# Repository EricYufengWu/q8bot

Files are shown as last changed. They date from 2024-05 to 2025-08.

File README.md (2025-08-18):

# Q8bot Quadruped

**03/03/2025 Update: Q8bot is now a research project at the [UCLA Robotics and Mechanisms Lab (RoMeLa)](https://www.romela.org/). The open-source nature of this project remains unchanged. We are working on an improved version of this platform and will potentially release it under a different name. Stay tuned!** 

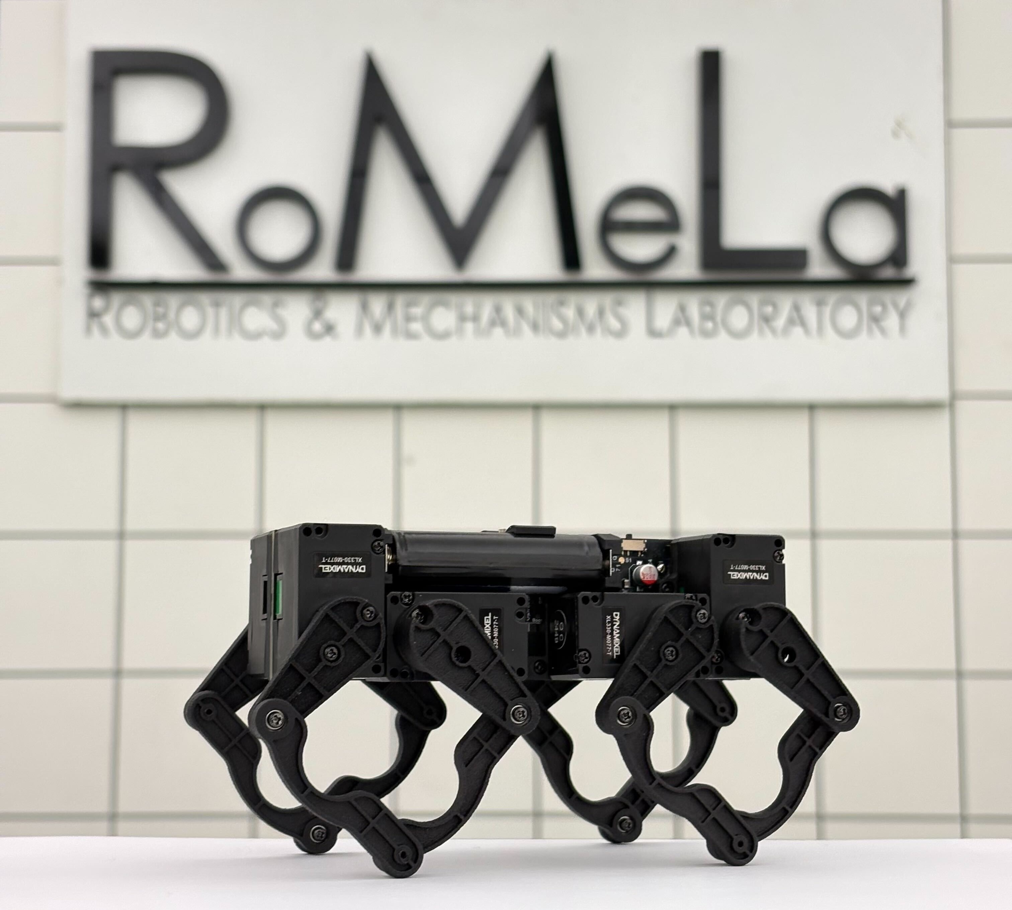
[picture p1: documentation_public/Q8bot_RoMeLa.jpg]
Q8bot (https://www.romela.org/)


## Featured Media & Demos

Q8bot was recently featured in a [tour video](https://youtu.be/FAo-BCnxW9A?si=LB-HlDlHGtaq-xd7&t=1208) by UnrealScience, a famous Korean science Youtube channel.

[This video](https://youtu.be/0dk7lYoITQw) demonstrates the latest capabilities of the robot, made possibly by ongoing improvements in software control and mechanical design.

See the detailed robot building process on [YouTube](https://youtu.be/YJDc1xAhaOI)!

Q8bot is lucky to be featured in a number of blog posts:
- Hackaday: https://hackaday.com/2024/10/29/little-quadruped-has-pcb-spine-and-no-wiring/#comments
- Hackster.io: https://www.hackster.io/news/a-step-up-for-diy-robotics-8b04a2320861?f=1
- Interesting Engineering: https://interestingengineering.com/innovation/palm-sized-quadruped-robot-redefines-design
- Techblog: https://www.techeblog.com/spot-robot-dog-q8bot/

## Publications
- Design: https://arxiv.org/abs/2508.01149
- Control & Data Acquisition: https://ieeexplore.ieee.org/abstract/document/11078123/

## Overview

Q8bot is a miniature quadruped robot with the size and weight comparable to a modern smartphone. This robot is capable of dynamic movements like walking, trotting, bounding, jumping, and more. It also has NO WIRES AND CABLES - everything is directly plugged into the center PCB, greatly reducing complexity, weight, and cost. The current **[Bill of Materials (BOM)](https://docs.google.com/spreadsheets/d/1M1K_Dghia-Mn2t4RStW8juN6r4e3I3OBy6M_fPFHzs8/edit?usp=sharing)**, without optimization, starts below $300. 

<p align="center">
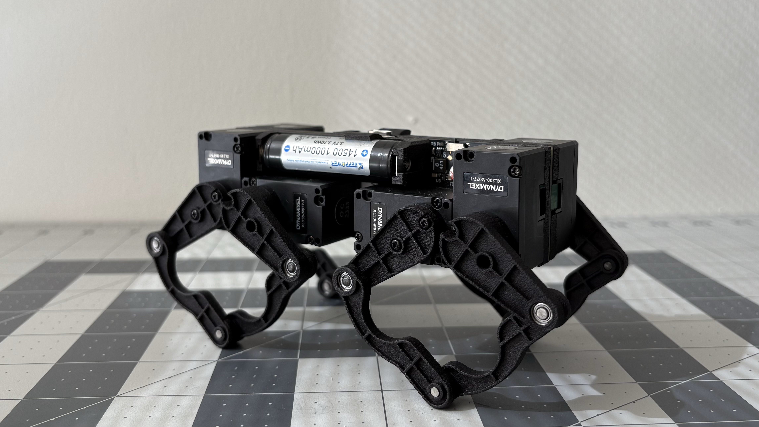
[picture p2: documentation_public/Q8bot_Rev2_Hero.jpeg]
  
  
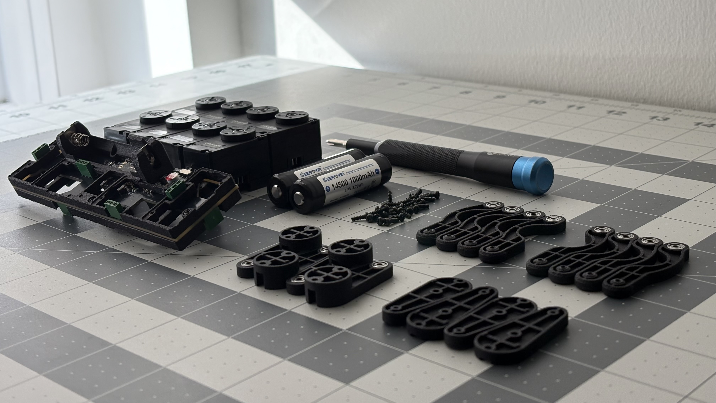
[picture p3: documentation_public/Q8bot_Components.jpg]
  
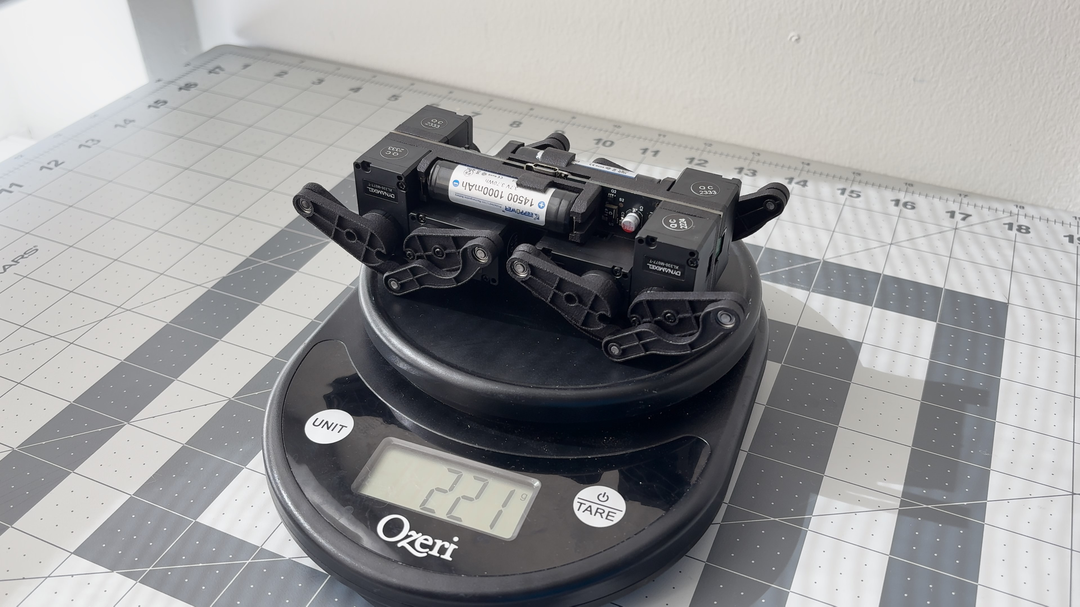
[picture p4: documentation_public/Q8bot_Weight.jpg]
  
</p>

Q8bot is 100% open source: In this repository, you will find everything you need - STEP, STL, Gerber, Schematics, bill of materials (BOM), instructions, and more - to build your own version. 

**You can now ordered the fully-assembled PCB via PCBWay!** This [project page](https://www.pcbway.com/project/shareproject/Q8bot_PCB_Robot_dfa65114.html) contains all of the assembly-related files (BOM, centroid, etc.) and simplifies the ordering process.

<p align="center">
    <a href="https://www.pcbway.com/project/shareproject/Q8bot_PCB_Robot_dfa65114.html">PCB from PCBWay</a>
</p>

I’m working on turning Q8bot into a purchasable kit, though I’m not sure when or if it will happen. In the meantime, I encourage you to build your own Q8bot! This palm-sized quadruped is perfect for robotics education, swarm robotics research, or simply as a fun engineering project. If you have any questions, feel free to reach out and I will try my best to help. 

Personal: yufeng.wu0902@gmail.com

School: ericyufengwu@ucla.edu

## Building Instruction

The building instructions have moved to a dedicated folder:

[Sourcing Components](building_instructions/sourcing_components.md)

[Assembling the Robot](building_instructions/robot_assembly.md)

[Software Setup](building_instructions/software_setup.md)

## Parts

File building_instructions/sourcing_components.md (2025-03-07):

# Components Sourcing Instructions

[**Sourcing Components**]()

[Assembling the Robot](robot_assembly.md)

[Software Setup](software_setup.md)

[Back to Project Page](https://github.com/EricYufengWu/q8bot)

**The complete bill of materials (BOM) of Q8bot can be accessed [here](https://docs.google.com/spreadsheets/d/1M1K_Dghia-Mn2t4RStW8juN6r4e3I3OBy6M_fPFHzs8/edit?usp=sharing)**. The links and prices are mainly for purchasing within the US. To accommodate different users, we've set up multiple "tiers" based on the tools you might have available. Please read the following sections carefully to choose the build configuration that works best for you. 

The BOM of this robot is so short that I can afford to explain every single component in detail :D

## Required Tools
This instruction assumes you have the following tools at a minimum:
- A PH-0 or JIS-1 screwdriver (I an iFixit Mako Driver Kit).
- A soldering iron with basic consumables (I used a Pinecil V2).
- A modern laptop capable of running Microsoft Visual Studio Code.
- A USB Type-A to Type-C (or Type-C to Type-C) cable for uploading firmware.
- Some masking tape or similar.

## Off-The-Shelf Components
These are the components you need to purchase regardless of build configurations.

[Dynamixel XL330-M077-T](https://www.robotis.us/dynamixel-xl330-m077-t/): You need a total of **8 motors** for the robot. Each motor comes with a set of M2 self-tapping screws, which will be used to assemble Q8bot.
<p align="center">
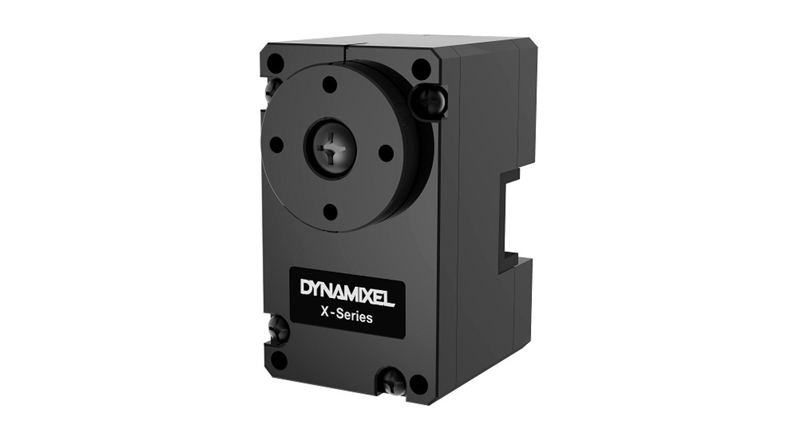
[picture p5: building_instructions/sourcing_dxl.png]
Dynamixel XL330-M077-T
    
</p>

[692ZZ Ball Bearing](https://www.amazon.com/uxcell-Groove-Bearings-Double-Shielded/dp/B082PR238V/ref=sr_1_2): You need a total of **12 bearings** with the trade number **692ZZ** (2mm x 6mm x 3mm). At the time of this writing, Amazon only sells them for pack of 10, so you'll end up with some extras. You can probably find cheaper alternatives on AliExpress or Ebay - any bearing with the same dimensions will work.

<p align="center">
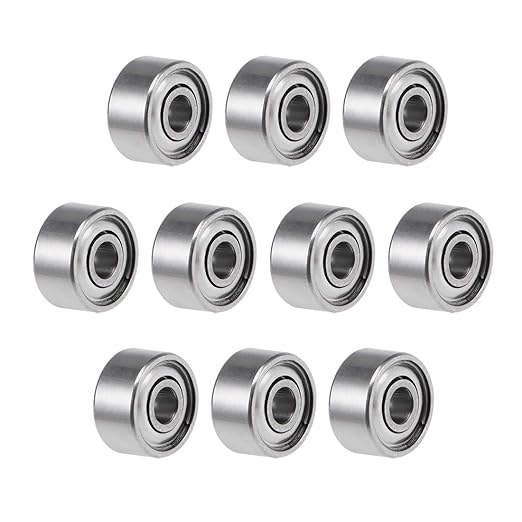
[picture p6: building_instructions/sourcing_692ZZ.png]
692ZZ Bearing
    
</p>

[14500 KeepPower 1000mAh P1450C2](https://illumn.com/14500-keeppower-1000mah-p1450c2-protected-button-top.html): You need **2 batteries** to run the robot and can purchase more pairs for hot-swapping. Keep in mind that these are Lithium-ion batteries in a AA form-factor, but **regular AA batteries will not work**. This particular model also has a built-in protection circuit so it is safer to work with.

<p align="center">
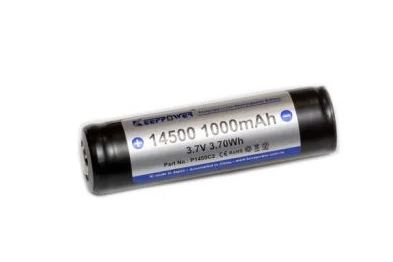
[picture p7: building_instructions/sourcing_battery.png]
KeepPower Battery
    
</p>

## Main PCB
There are two options for acquiring the main PCB for Q8bot.

### Option 1: Purchase A Fully-Assembled Board from PCBWay
  [This link](https://www.pcbway.com/project/shareproject/Q8bot_PCB_Robot_dfa65114.html) takes you to a PCBWay project page, contains all of the assembly-related files (BOM, centroid, etc.). You can simply  select "PCB+Assembly" and order the fully-assembled PCB (including headers and the micro-controller).

<p align="center">
    <a href="https://www.pcbway.com/project/shareproject/Q8bot_PCB_Robot_dfa65114.html">PCB from PCBWay</a>
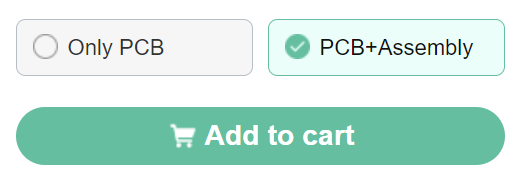
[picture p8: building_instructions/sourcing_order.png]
Ordering
    
</p>

However, you will still need to purchase some battery clips which will go into the 3D-printed main frames to hold the batteries. [This link](https://www.digikey.com/short/8w05tttf) directs you to a DigiKey shopping cart that contains 2x 1087-1 and 2x 1087-2 from Keystone Electronics.

<p align="center">
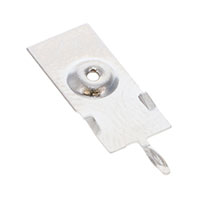
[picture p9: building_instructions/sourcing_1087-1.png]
    
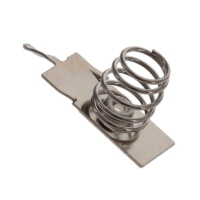
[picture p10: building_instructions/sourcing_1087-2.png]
    
</p>

### Option 2: Purchase Components and Reflow Yourself
You can order the blank PCB from JLC, PCBWay, or similar, and order the components separately to assemble the PCB youself. The zipped Gerber files, along with a read-friendly pick-and-place file, can be found under the `/PCBA` folder. Remember to also order stencils (top and bottom) when purchasing the blank PCBs. 

I used a [MHP50](https://www.adafruit.com/product/5903) mini hot plate and a stencil holder setup similar to [this one](https://youtu.be/F9zNtQTpbms?si=rfB_CtxsjbDME_TU). See my [YouTube video](https://youtu.be/YJDc1xAhaOI) for details. 

<p align="center">
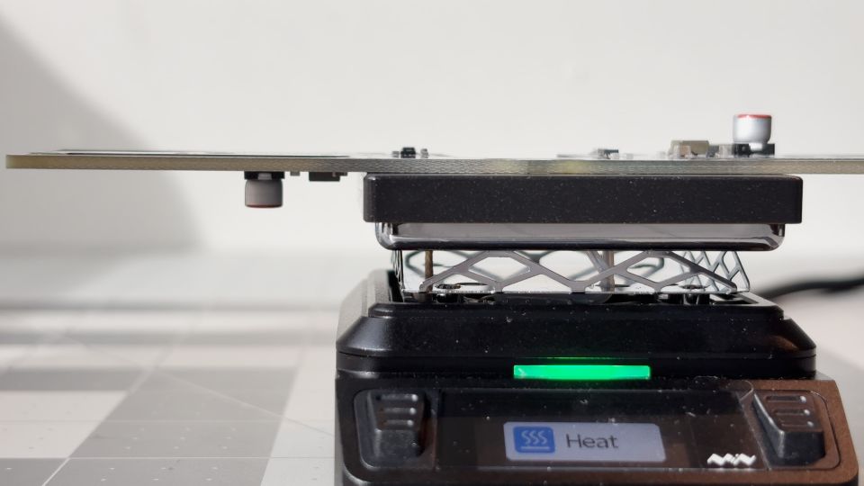
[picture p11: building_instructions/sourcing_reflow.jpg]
Reflow
    
</p>

[This link](https://www.digikey.com/short/n7vrz77m) directs you to a DigiKey shopping cart that contains all required PCB components, including the battery clips from earlier.

## 3D-Printed Parts
There are 2 options for 3D-printing parts for Q8bot. Regardless of outsourcing or printing them yourselves, you will need the following quantity to build 1x Q8bot. It never hurts to print/order some extras in case the robot breaks.
- `Q8bt_Frame`: Print 2.
- `Q8bot_LL_Left`: Print 4.
- `Q8bot_LL_Right`: Print 4.
- `Q8bot_UL1`: Print 4.
- `Q8bot_UL2`: Print 4.

### Option 1: Order MJF parts from Online Vendors
Multi Jet Fusion (MJF) is an isotropic 3D-printing technology similar to SLS. Many domestic and international companies offer printing service with relatively affordable price. To order, you typically need to upload the .STL files in the `/CAD/Q8_VX.X_MJF` folder to the vendor's website and configure the materials and quantity. I ordered the MJF parts together with my JLCPCB order to simplify the purchasing process.

### Option 2: 3D-Print Yourself using FDM
If you own a Bambu Lab, Prusa, or similar 3D-printer, you can print the parts yourself by downloading and slicing the files under `/CAD/Q8_VX.X_FDM`. I printed mine on a Bambu Lab A1 mini with the default 0.12mm settings. **The cost of filament is less than $1 for a $20 spool.**

Here is a table comparing MJF and FDM 3D-printed parts:

| MJF Outsourcing | FDM Print-it-Yourself |
|---|---|
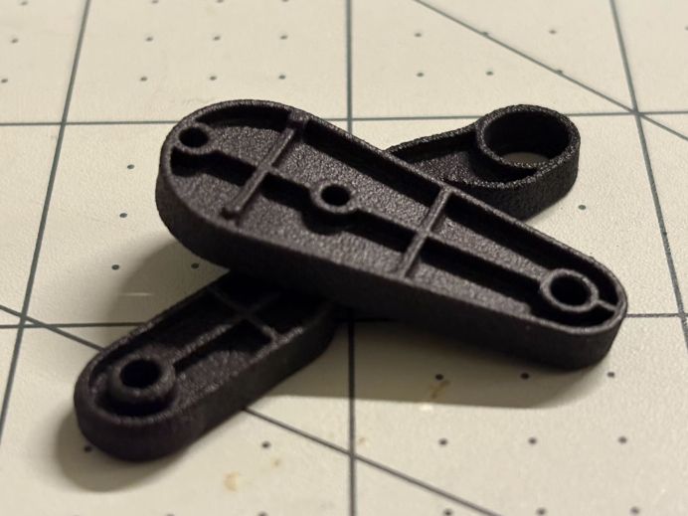
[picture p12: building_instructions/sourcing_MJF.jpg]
|  ||
| More expensive :x: | Less expensive :white_check_mark: |
| Saves time :white_check_mark: | Takes more time :x: |
| Surface finish gives a "product" vibe :white_check_mark: | Visible layer lines on parts :x: |
| Has extra geometry that makes assembly easier :white_check_mark: | No extra geometry :x: |
| Difficult to replace :x: | Easy to re-print and modify :white_check_mark: |
| Breaks first to protect motors* | Motors might break due to transferred impact* |

_*Not rigorously tested. Robot survives 1-meter drop during preliminary testing_

## Other Recommended Components
**Li-ion battery charger:** If you don't already have one, you probably also want to pick up a charger like [this one](https://www.amazon.com/EBL-Battery-Charger-Rechargeable-Technology/dp/B01D9TUL8Y/). In the future, I plan to add battery charging functionality to the PCB in the next iteration so you no longer have to buy a separate charger.

**ESPNow Dongle:** The current software architecture uses an ESP32C3 microcontroller connected to the laptop to wirelessly communicate with the robot. You can build an optional USB dongle by following instructions [here](https://github.com/EricYufengWu/ESPNowDongle). 

<p align="center">
    Dongle
</p>

**Dynamixel U2D2:** DYNAMIXELs are smart servo motors that require configuration to work properly on Q8bot. I’ve provided a simple firmware that guides you through the required setup without extra hardware (see [robot_assembly](robot_assembly.md)). However, for easier debugging and troubleshooting, I highly recommend purchasing the [U2D2](https://www.robotis.us/u2d2/) and [U2D2 Power Hub](https://www.robotis.us/u2d2-power-hub-board-set/). This setup allows you to configure individual DYNAMIXEL motors directly from your laptop, which is more convenient compared to using the ESP32.

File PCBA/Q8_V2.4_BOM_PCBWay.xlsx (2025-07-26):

 |  |  | Q8_V2.3 BOM
Item # | *Designator | *Qty | Manufacturer | *Mfg Part # | Description / Value | *Package/Footprint | Type | Your Instructions / Notes
1 | R8 | 1 | YAGEO | RC0603FR-0722RL | RES 22 OHM 1% 1/10W 0603 | 0603 | SMD | Generic chip resistor OK
2 | R1 | 1 | YAGEO | RC0603FR-07200RL | RES 200 OHM 1% 1/10W 0603 | 0603 | SMD | Generic chip resistor OK
3 | R2, R3, R4, R6, R7 | 5 | YAGEO | AF0603FR-0710KL | RES 10K OHM 1% 1/10W 0603 | 0603 | SMD | Generic chip resistor OK
4 | R5, R9 | 2 | YAGEO | AC0603FR-071KL | RES 1K OHM 1% 1/10W 0603 | 0603 | SMD | Generic chip resistor OK
5 | C1 | 1 | YAGEO | CC0603KRX7R8BB104 | CAP CER 0.1UF 25V X7R 0603 | 0603 | SMD | Generic >25V X5R/X7R capacitors OK
6 | C2, C3, C7, C8 | 4 | YAGEO | CC0805KKX5R8BB106 | CAP CER 10UF 25V X5R 0805 | 0805 | SMD | Generic >25V X5R/X7R capacitors OK
7 | C5 | 1 | YAGEO | CC0603KRX5R8BB105 | CAP CER 1UF 25V X5R 0603 | 0603 | SMD | Generic >25V X5R/X7R capacitors OK
8 | C6 | 1 | YAGEO | CC0603KRX7R9BB103 | CAP CER 10000PF 50V X7R 0603 | 0603 | SMD | Generic >25V X5R/X7R capacitors OK
9 | C4, C9 | 2 | Würth Elektronik | 865080342006 | CAP ALUM 47UF 20% 16V SMD | Radial, Can - SMD | SMD
10 | D1 | 1 | Lite-On Inc. | LTST-C190KRKT | LED RED CLEAR CHIP 0603 | 0603 | SMD | Generic red clear LED OK
11 | D2 | 1 | Onsemi | NSR0320MW2T1G | DIODE SCHOTTKY 20V 1A SOD323 | SC-76, SOD-323 | SMD
12 | Q1, Q2 | 2 | Onsemi | MCH6351-TL-W | MOSFET P-CH 12V 9A 6MCPH | 6-MCPH | SMD
13 | S1 | 1 | E-Switch | EG1215AA | SWITCH SLIDE SPDT 25MA 24V | Switch SMD | SMD
14 | U2 | 1 | Nexperia | 74LVC2G241GT,115 | IC BUFFER NON-INVERT 5.5V | 8XSON | SMD
15 | U3, U5 | 2 | Texas Instruments | TPS610333DRLR | IC REG BOOST ADJ 5A | SOT583 | SMD
17 | U4 | 1 | Maxim Integrated | MAX17043G+T | IC 2-WIRE FG MODEL GAUGE LO BATT | 8-TDFN | SMD
18 | L1, L2 | 2 | Coilcraft | XGL4020-471MEC | FIXED IND 470NH 19.7A 5.1MOHM SM | 1616 | SMD
19 | U1 | 1 | Seeed | 113991054 | SEEEDSTUDIO XIAO ESP32C3 NO HDRS | SMD | SMD | Please solder the component upside-down, so that the buttons and USBC connectors faces down. Hand-soldering is ok for this component.
20 | J1 - J8 | 8 | TE Connectivity | 215297-3 | RECEPTACLE STRIP 3P 2.54MM PITCH | 1x3 2.54mm | Through-hole | Height range of the header must be between 7mm and 7.9mm. Please note the silkscreen marking side is where the components should be placed. The soldering joints should be at the opposite side of the silkscreen. There are a total of 8 connectors, 4 on each side according the the silkscreen markings.
21 | J9 | 1 | JST | BM04B-SRSS-TBT(LF)(SN) | CONN HEADER SMD 4POS 1MM | JST SH | SMD | Alternative manufacturer OK
22 | BT1, BT2 | 2 | Custom | NA | Custom battery part | NA | DNP | Do not place
Need a quick and accurante quote? Need an efficient production? Please read SMT Ordering Necessary Files & Info in 1 minute. Thank you very much! (https://www.pcbway.com/smt_ordering_guide.html)
Click for Instructions on How to Create a BOM (https://www.pcbway.com/blog/PCB_Assembly/How_to_Build_a_BOM__Bill_Of_Materials_.html)

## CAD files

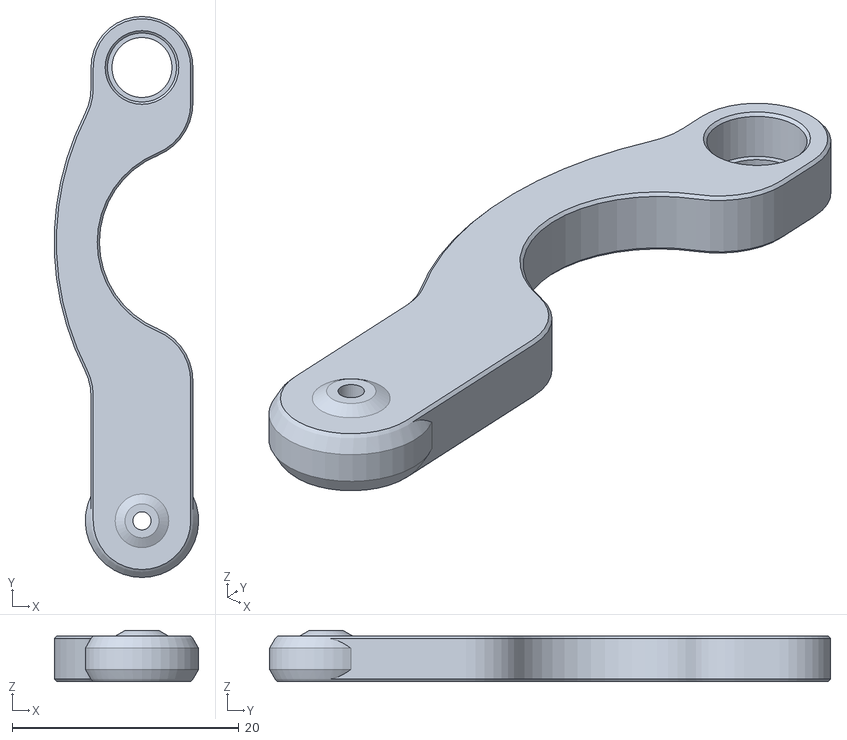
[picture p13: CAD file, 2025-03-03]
CAD/Q8_V2.4_FDM/PLA_Lower_Leg_Right_PRINT4.STL
12.7 x 49.5 x 4.50

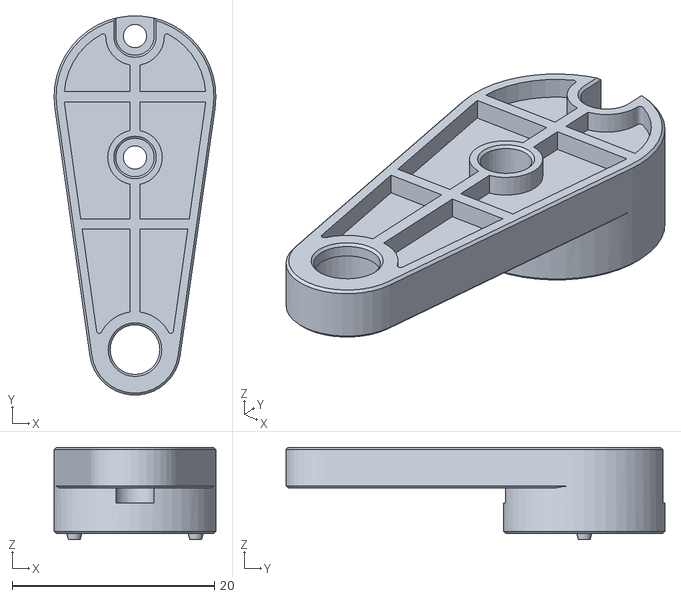
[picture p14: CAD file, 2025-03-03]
CAD/Q8_V2.4_MJF/MJF_Upper_Leg_Tall_PRINT4.STL
16.0 x 37.5 x 9.10

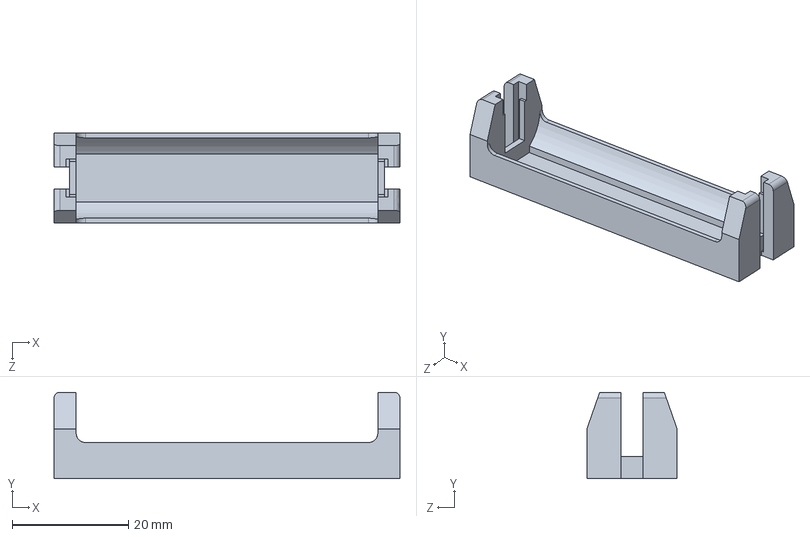
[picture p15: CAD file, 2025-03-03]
CAD/SolidWorks Source File/Batt_Case_keystone-PN1087_20250303export.SLDPRT
59.4 x 14.9 x 15.5 mm

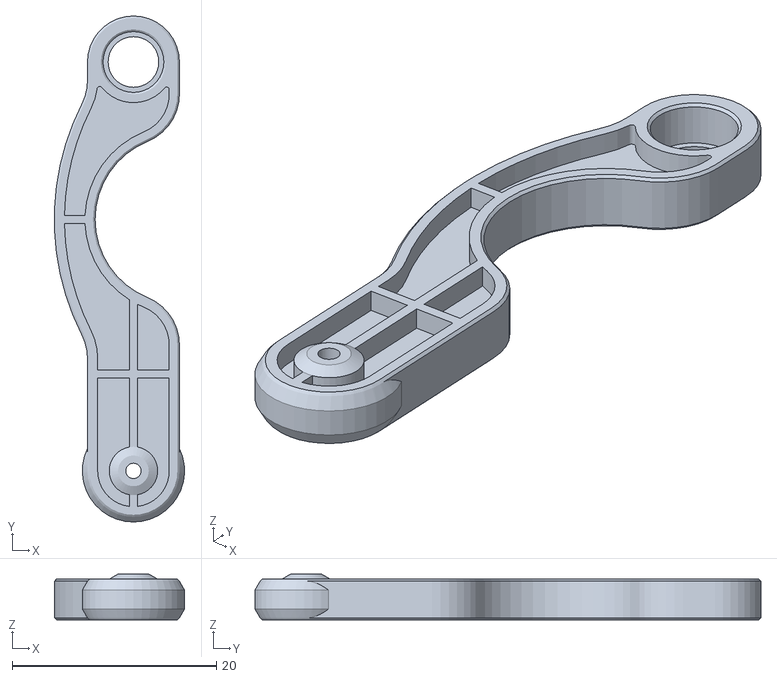
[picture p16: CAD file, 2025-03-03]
CAD/Q8_V2.4_MJF/MJF_Lower_Leg_Right_PRINT4.STL
12.7 x 49.5 x 4.50

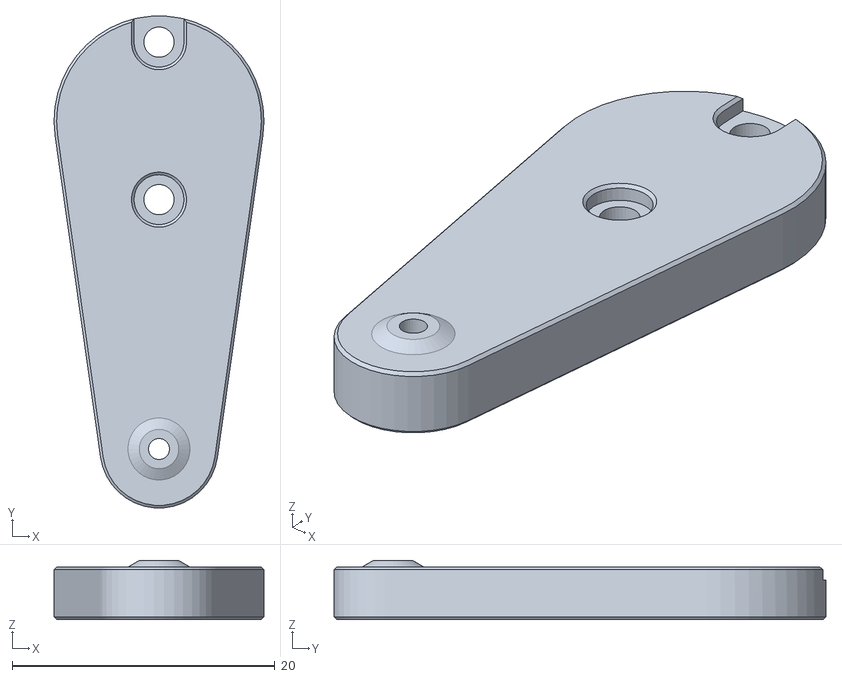
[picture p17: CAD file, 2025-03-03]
CAD/Q8_V2.4_FDM/PLA_Upper_Leg_Short_PRINT4.STL
16.0 x 37.5 x 4.50

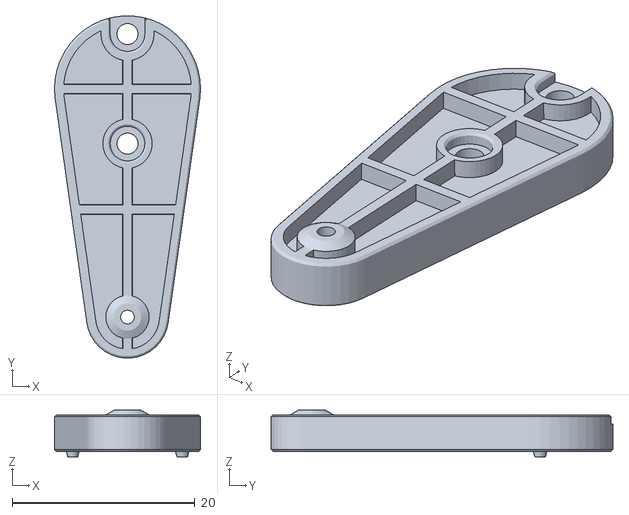
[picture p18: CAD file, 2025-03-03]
CAD/Q8_V2.4_MJF/MJF_Upper_Leg_Short_PRINT4.STL
16.0 x 37.5 x 5.10

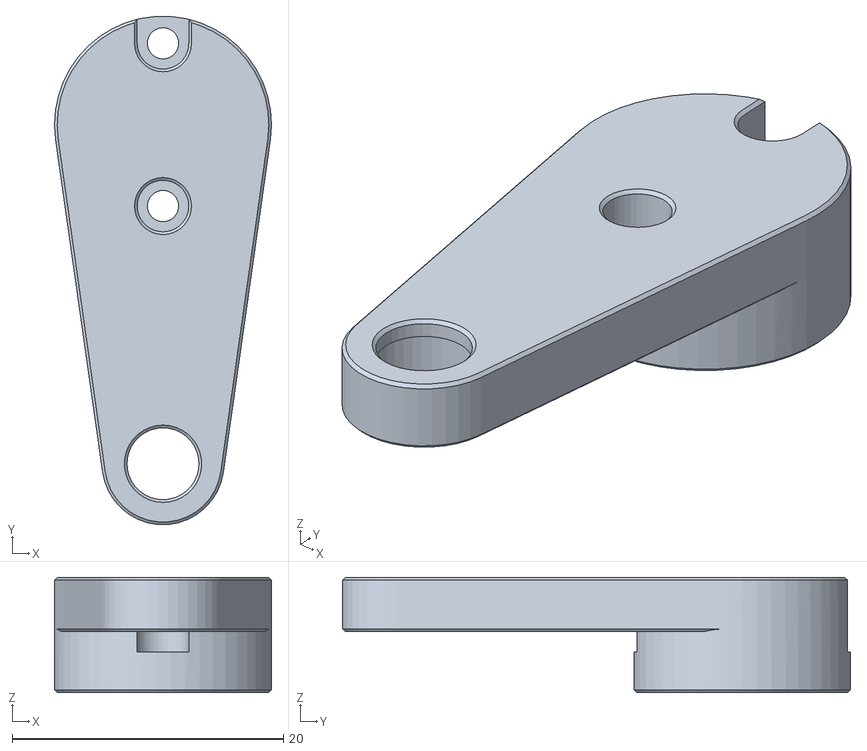
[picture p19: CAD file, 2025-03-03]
CAD/Q8_V2.4_FDM/PLA_Upper_Leg_Tall_PRINT4.STL
16.0 x 37.5 x 8.50

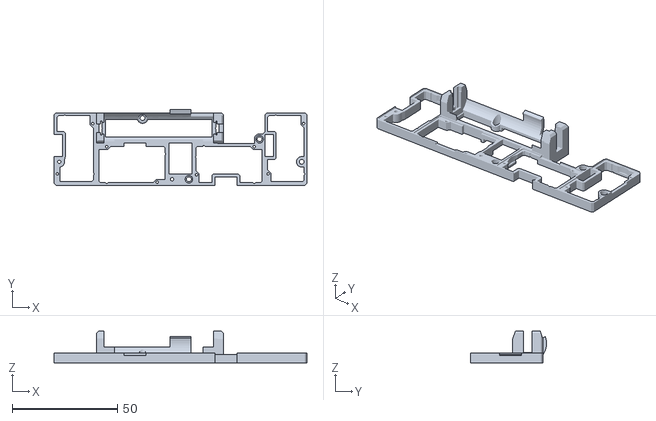
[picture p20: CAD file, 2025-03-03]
CAD/Q8_V2.4_MJF/MJF_Frame_PRINT2.STL
120.0 x 36.1 x 15.1

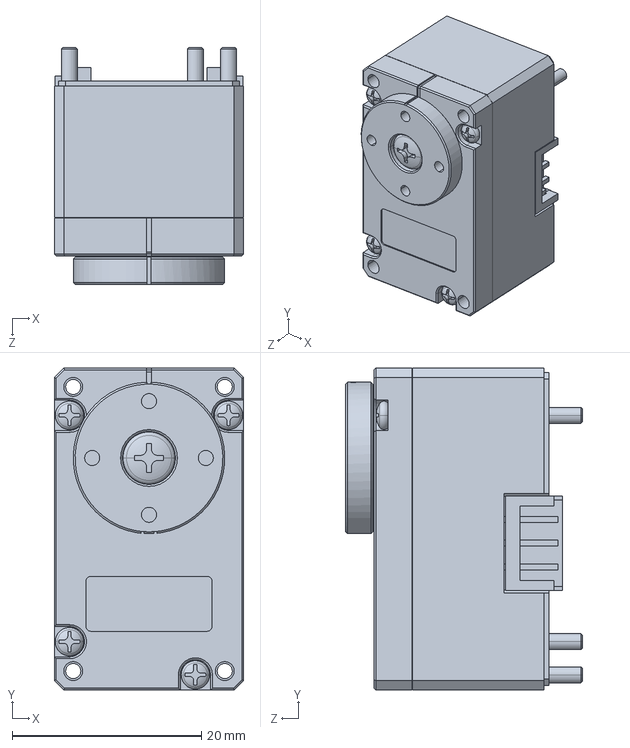
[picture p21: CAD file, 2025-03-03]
CAD/SolidWorks Source File/XL330_M077_T_20250303export.SLDPRT
20.0 x 34.0 x 25.0 mm

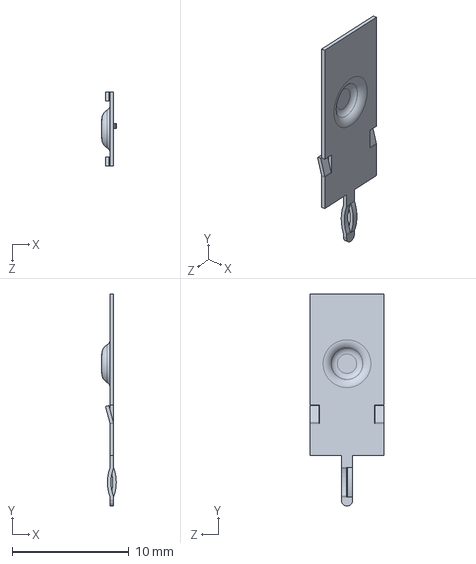
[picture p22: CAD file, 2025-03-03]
CAD/SolidWorks Source File/Batt_Clip_keystone-PN1087-1_20250303export.SLDPRT
1.24 x 18.2 x 6.35 mm

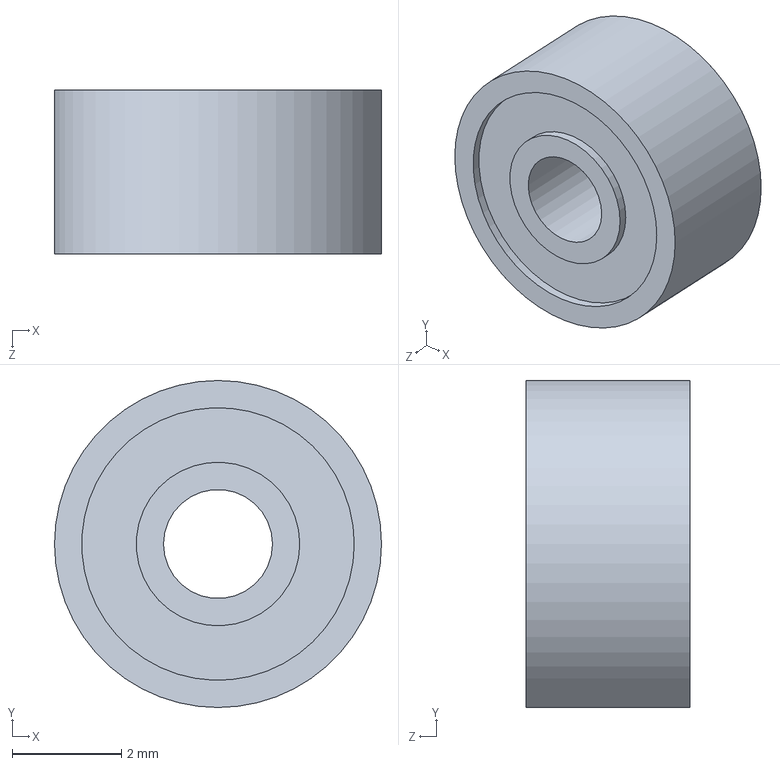
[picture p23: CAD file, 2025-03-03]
CAD/SolidWorks Source File/692ZZ_Ball_Bearing_20250303export.SLDPRT
6.00 x 6.00 x 3.00 mm

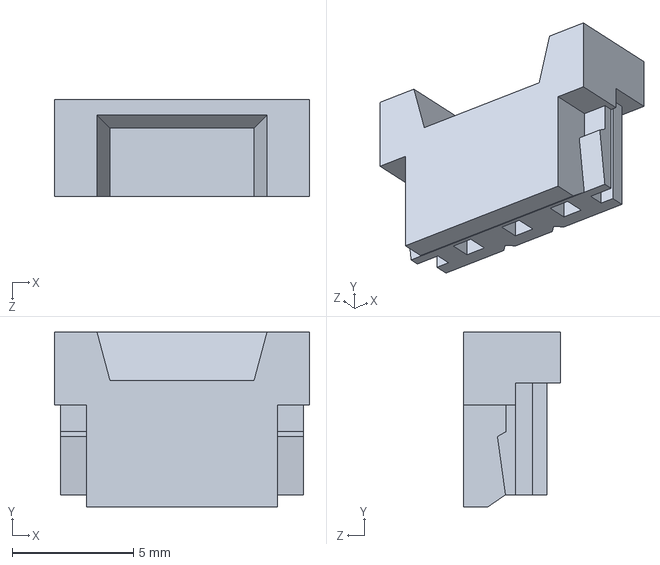
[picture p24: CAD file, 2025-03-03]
CAD/SolidWorks Source File/Conn_EHR-3_20250303export.SLDPRT
10.5 x 7.20 x 4.00 mm

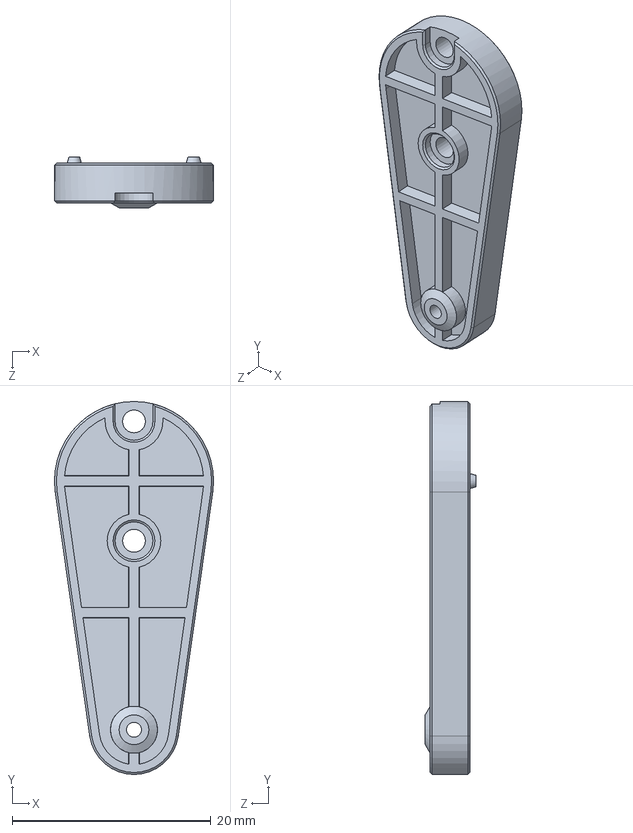
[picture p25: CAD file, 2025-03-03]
CAD/SolidWorks Source File/Q8bot_Upper_Leg_20250303export.SLDPRT
16.0 x 37.5 x 5.10 mm

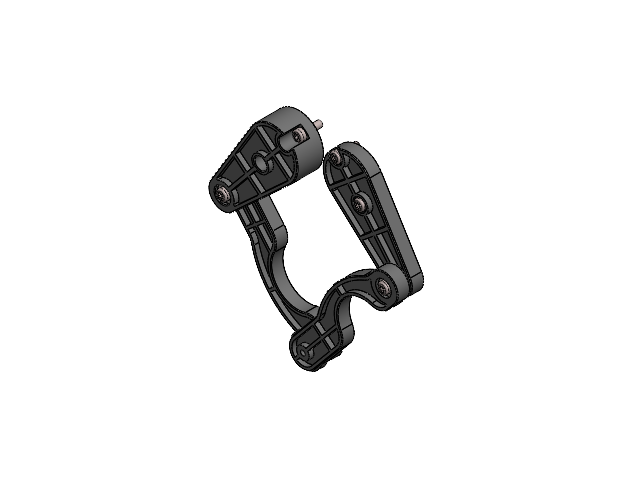
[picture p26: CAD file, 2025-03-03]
CAD/SolidWorks Source File/Q8bot_Leg_SubAssm_20250303export.SLDASM
Q8bot_Upper_Leg x 2
Q8bot_Lower_Leg x 2
M2_Tapping_Screw x 7
692ZZ_Ball_Bearing x 3

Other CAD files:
CAD/Q8_V2.4_FDM/PLA_Lower_Leg_Left_PRINT4.STL
CAD/SolidWorks Source File/Q8bot_Lower_Leg_20250303export.SLDPRT
CAD/Q8_V2.4_FDM/Q8bot_Frame_FDM_PRINT2.STL
CAD/Q8_V2.4_MJF/MJF_Lower_Leg_Left_PRINT4.STL
CAD/SolidWorks Source File/Batt_Clip_keystone-PN1087-2_20250303export.SLDPRT
CAD/SolidWorks Source File/Batt_KeepPower_14500_P1450C2_20250303export.SLDPRT
CAD/SolidWorks Source File/M2_Tapping_Screw_20250303export.SLDPRT
CAD/SolidWorks Source File/Q8_PCB_Placeholder_20250303export.SLDPRT
archived_designs/CAD/Q8_V2.2_FDM/Q8bot_AllParts_A1Mini.gcode.3mf
archived_designs/CAD/Q8_V2.2_FDM/Q8bot_Frame_FDM_PRINT2.STL
archived_designs/CAD/Q8_V2.2_FDM/Q8bot_LL_Left_FDM_PRINT4.STL
archived_designs/CAD/Q8_V2.2_FDM/Q8bot_LL_Right_FDM_PRINT4.STL
archived_designs/CAD/Q8_V2.2_FDM/Q8bot_UL1_FDM_PRINT4.STL
archived_designs/CAD/Q8_V2.2_FDM/Q8bot_UL2_FDM_PRINT4.STL
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

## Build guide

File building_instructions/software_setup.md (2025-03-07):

# Software Setup Instructions

[Sourcing Components](sourcing_components.md)

[Assembling the Robot](robot_assembly.md)

[**Software Setup**]()

[Back to Project Page](https://github.com/EricYufengWu/q8bot)

## Software Overview

Please excuse my messy code as I am a mechanical engineer by training :D

Currently, all computation regarding gait generation and FK/IK happens on the laptop. The laptop talks to the robot remotely via another Seeed Studio XIAO ESP32C3, sending raw joint angles as rapidly as possible using the ESPNow protocol. In the future, the hope is to move the gait generation code to the robot's onboard ESP32 for improved control.

<p align="center">
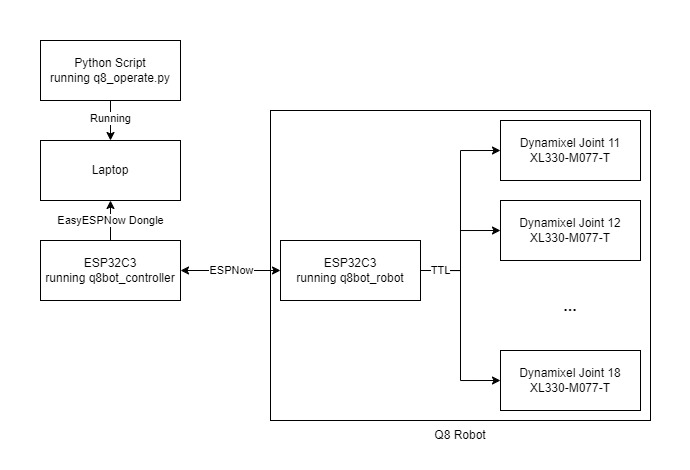
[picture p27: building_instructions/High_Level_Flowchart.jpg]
High level flowchart
    
</p>

## Seeed Studio XIAO MCU Setup (Robot + Controller)

The microcontroller part of the code is developed in [PlatformIO](https://platformio.org/). If you haven't used it before, please refer to their official documentation and tutorials to setup the environment. Someone has also tried converting PlatformIO projects to Arduino IDE script [here](https://runningdeveloper.com/blog/platformio-project-to-arduino-ide/).

Different firmware need to be uploaded to Q8bot ("robot") and the separate Seeed Studio XIAO ESP32C3 ("controller"): `q8bot_cpp/q8bot_robot` and `q8bot_cpp/q8bot_controller`. Before they are ready to upload, you need to:
- Navigate to `q8bot_cpp/q8bot_robot/main.cpp` and update the MAC address to match your controller
- Navigate to `q8bot_cpp/q8bot_controller/main.cpp` and update the MAC address to match your robot.
- A quick way to find the MAC address of your device is by selecting the specific COM port in PlatformIO.
<p align="center">
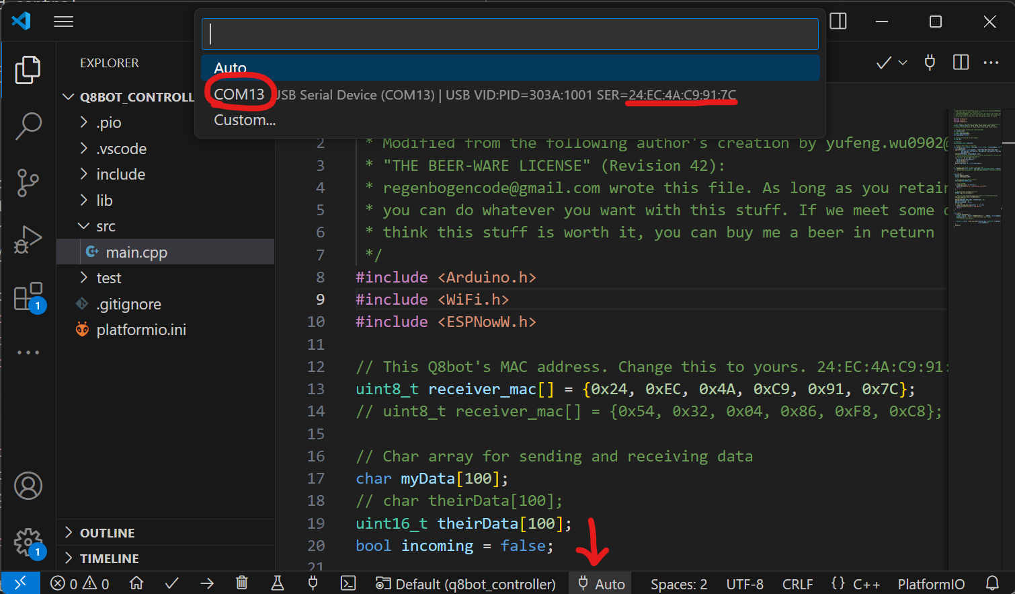
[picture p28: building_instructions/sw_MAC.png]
    
</p>

Upload `q8bot_cpp/q8bot_robot` to the Q8bot PCB, and upload `q8bot_cpp/q8bot_controller` to the controller ESP32C3. The process will be similar to steps 10 - 13 in [Robot Assembly](robot_assembly.md), 

## Python Setup
Install python locally on your computer if you have not already. The simplest way is through the [official website](https://www.python.org/downloads/) (the latest version will do). **Make sure to check the "add python.exe to PATH" option.**
<p align="center">
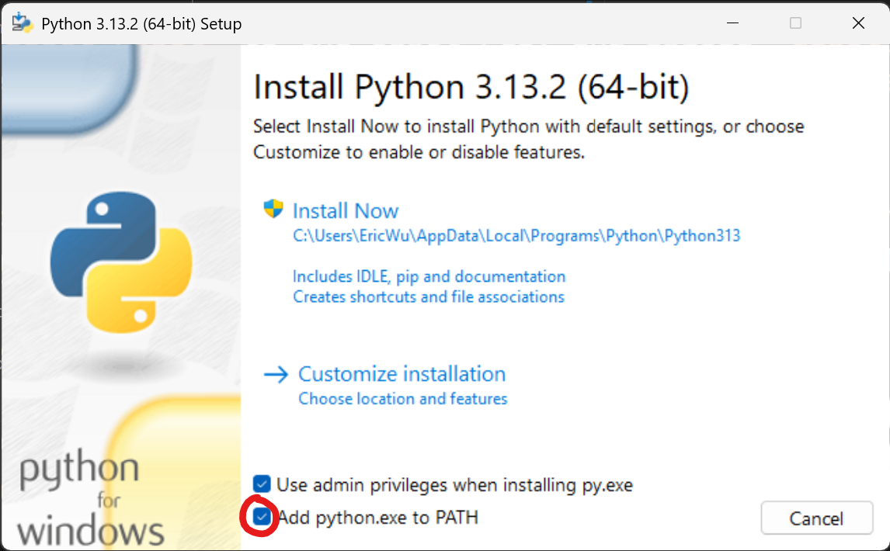
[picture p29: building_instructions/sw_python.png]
    
</p>

It's is best to set up a virtual environment to prevent dependency conflicts between different projects.

Using a terminal of your choise, navigate to the `/q8bot_python` folder and run the following to create a virtual environment for your project:

    python -m venv venv

In the same directory, activate the virtual environment.

    .\venv\Scripts\activate

In the same directory, run the following:

    pip install --upgrade --force-reinstall -r requirements.txt

This will force install necessary dependencies in your venv only (there aren't alot so you mey have already had all libraries installed).

## Running the Robot
Attach the batteries to the robot (double-check polarity!). Power on the robot with the onboard slide switch and you should see the onboard LED light up.

Plug in the controller board to your laptop/PC.

Navigate to `/q8bot_python/q8bot` folder and run:

    python operate.py

If everything works, you should see a small pygame window pop up and the robot move its joints to their initial location. Robot keyboard control instructions are as follows:
- WASD for robot movement. Q and E are used to partial turning in amber gait.
- G two cycle between different gaits.
- J for jumping.
- R for resetting stance, size, etc.
- The terminal/console will output useful information depending on your input.

Have fun!

## Appendix

Here's a rough overview to the logic behind the python script (might not be accurate as I keep adding features)

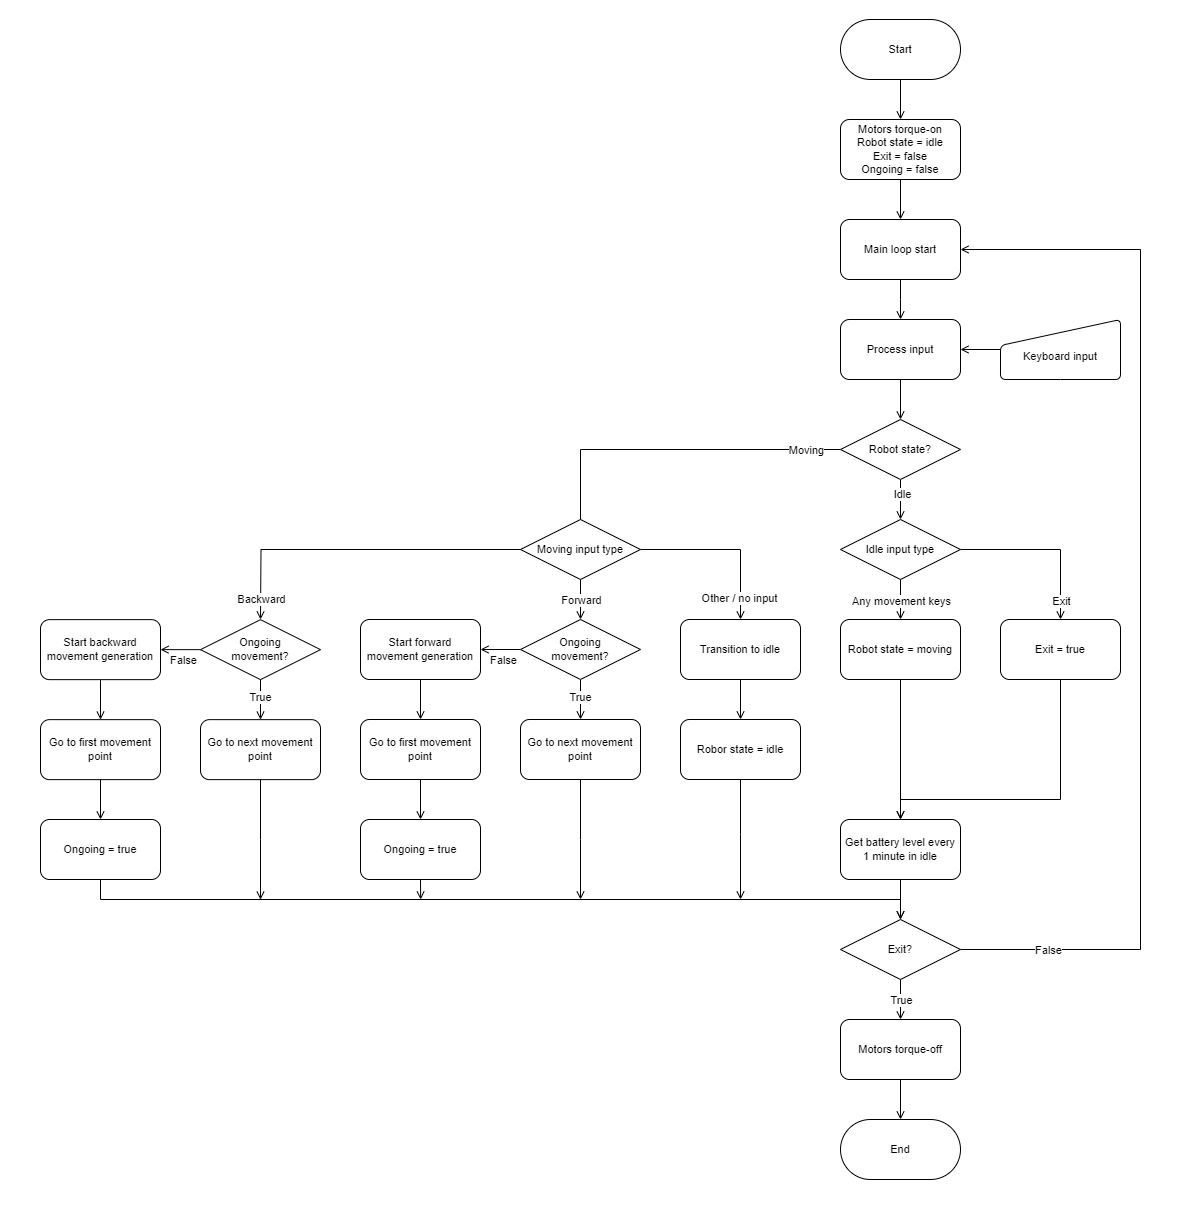
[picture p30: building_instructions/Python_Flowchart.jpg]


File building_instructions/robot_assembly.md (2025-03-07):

# Robot Assembly Instructions

[Sourcing Components](sourcing_components.md)

[**Assembling the Robot**]()

[Software Setup](software_setup.md)

[Back to Project Page](https://github.com/EricYufengWu/q8bot)

## Before You Begin:

- This instruction assume that you have either: (a) purchased the fully-assembled Q8bot PCB from PCBWay, or (b) reflow soldered the PCB yourself following the information found in the [`/PCBA`](../PCBA/) folder.

- If you are stuck or find the instruction confusing, please refer to the latest CAD model. If you still have trouble understanding, feel free to contact the author for clarification.

- If you are assembling the robot with brand new DYNAMIXEL motors, have a laptop ready to upload a simple firmware for motor configuration.

## Assembly Time!

1. Gather your components. From left right, top to down:
    - 2x Lithium-ion batteries
    - 3D-printed parts
    - 12x 692ZZ ball bearings
    - Battery clips
    - Separate Seeet Studio XIAO ESP32C3 (connect to PC for wireless control)
    - Fully-assembled Q8bot PCB
    - 8x brand new Dynamixel XL330-M077-T (which contains the screws needed for assembly)
<p align="center">
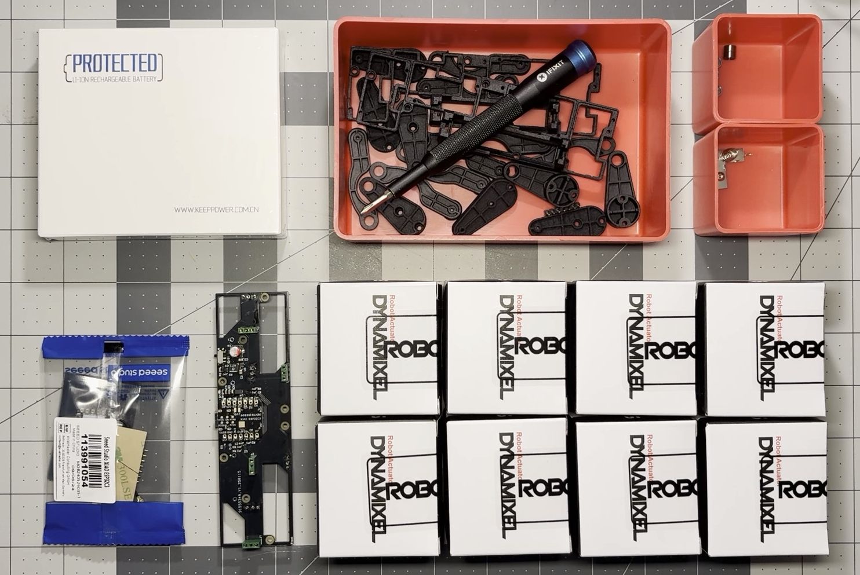
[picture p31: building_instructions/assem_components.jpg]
Components
    
</p>

* Here is another look at the components with all package removed. Note that we will only use the 6mm screws that came with the DYNAMIXEL motors. It would be a good idea to start charging your batteriesso that they will be ready later in the assembly process.
<p align="center">
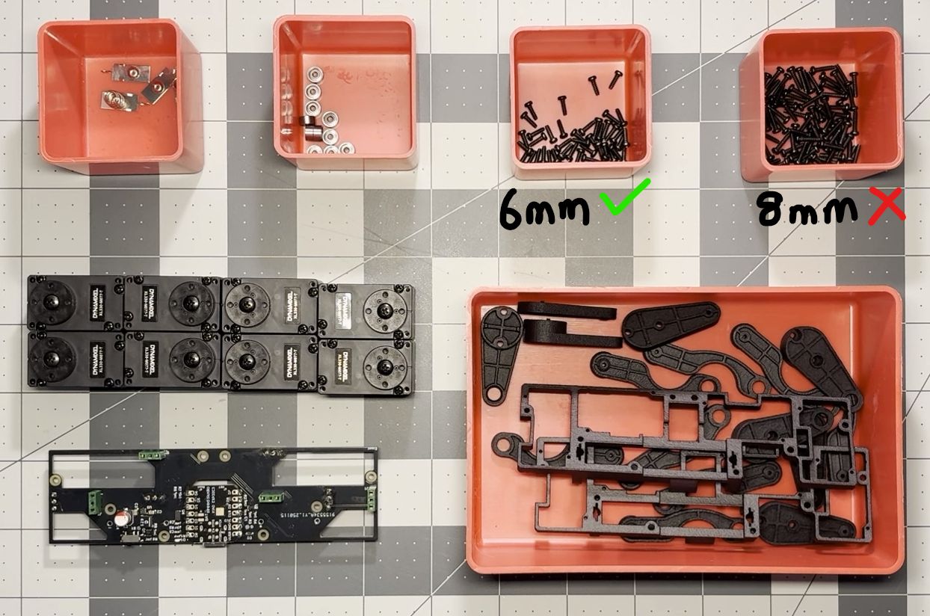
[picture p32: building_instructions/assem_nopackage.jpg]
    
</p>

2. Attach battery clips to the main frames. Double-check location: If holding the part with the battery geometry on the left side as shown, the negative clip (with spring) should be on the left side and the positive clip (flat) should be on the right, with the notch facing inward. Repeat this step for the second, identical frame.
<p align="center">
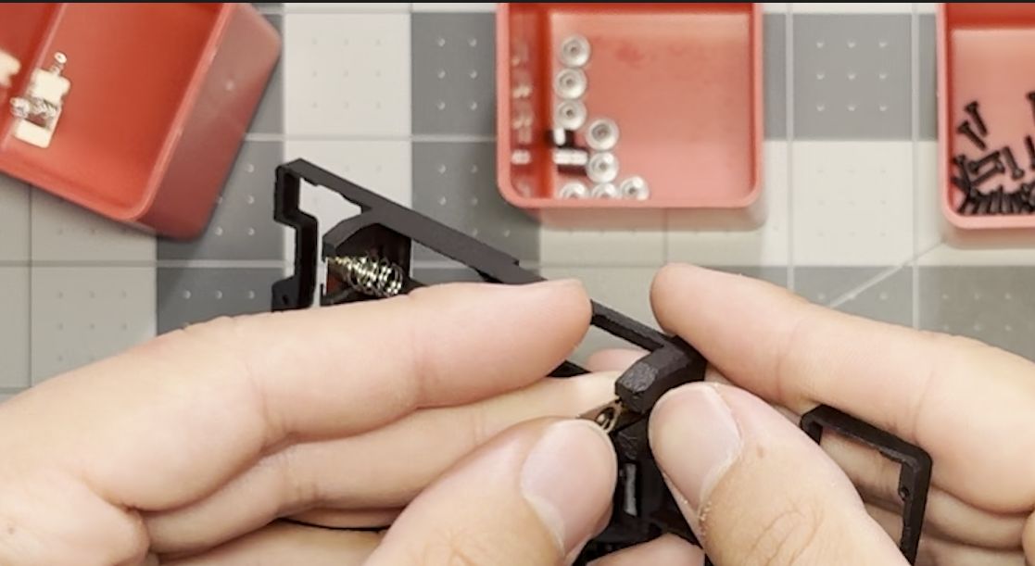
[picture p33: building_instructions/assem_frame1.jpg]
    
</p>
<p align="center">
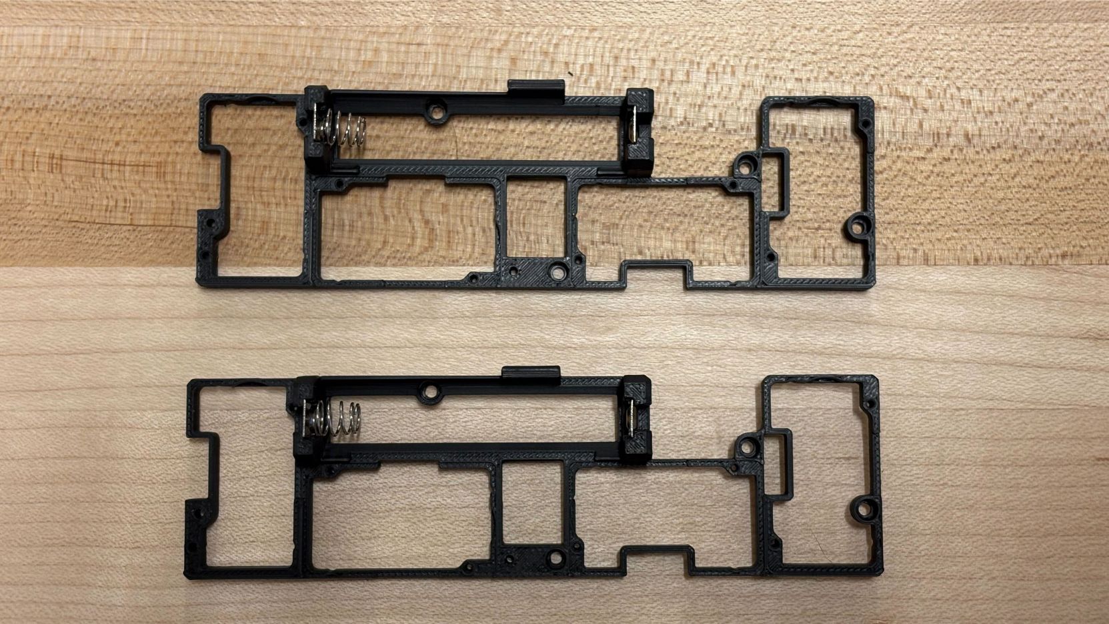
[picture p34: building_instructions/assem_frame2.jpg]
    
</p>

3. Attach the main frame to the center PCB using 8 M2x6mm self-tapping screws that came with the DYNAMIXEL motors.
<p align="center">
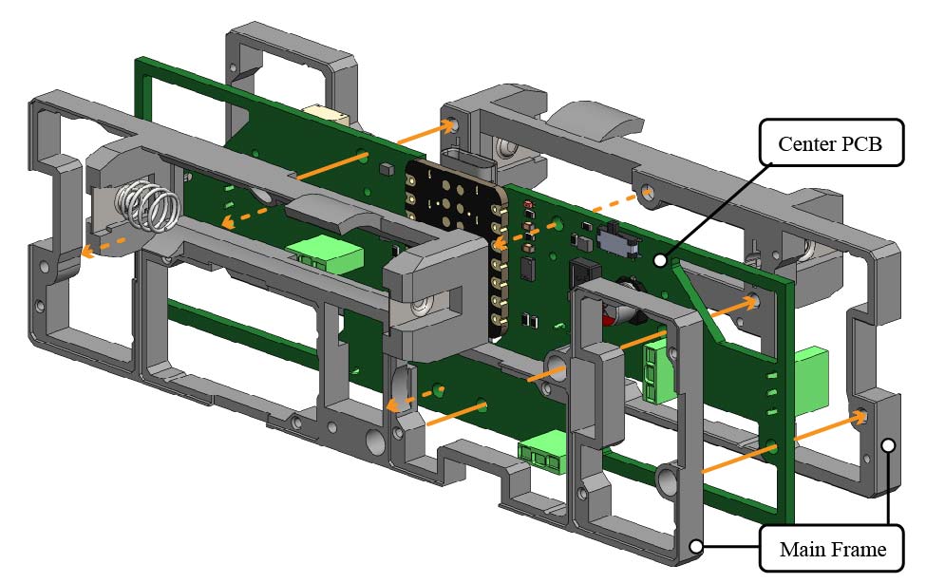
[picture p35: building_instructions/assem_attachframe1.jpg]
Attach Frames
    
</p>
<p align="center">
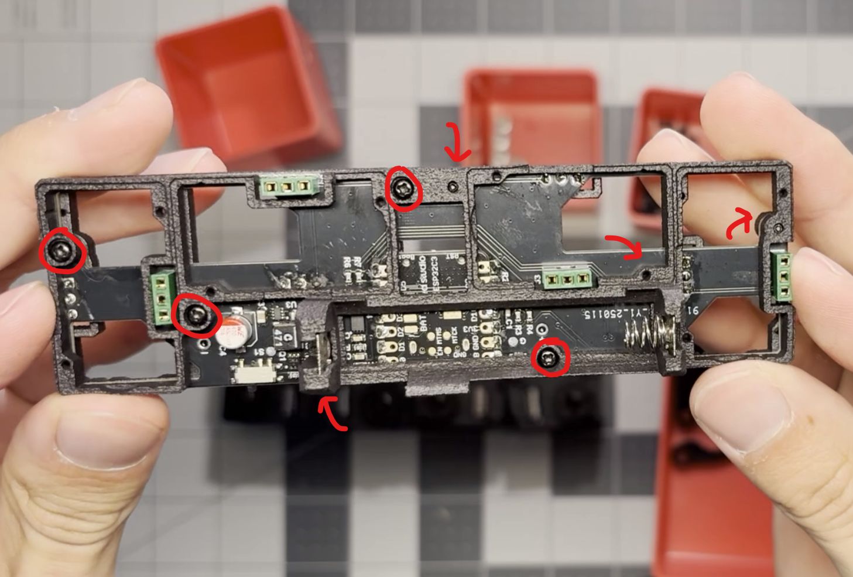
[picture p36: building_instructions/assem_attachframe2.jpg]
Attach Frames
    
</p>

4. Solder the battery clips to the PCB. Be careful not to melt the 3D-printed frame parts. Using some solder flux could be helpful.
<p align="center">
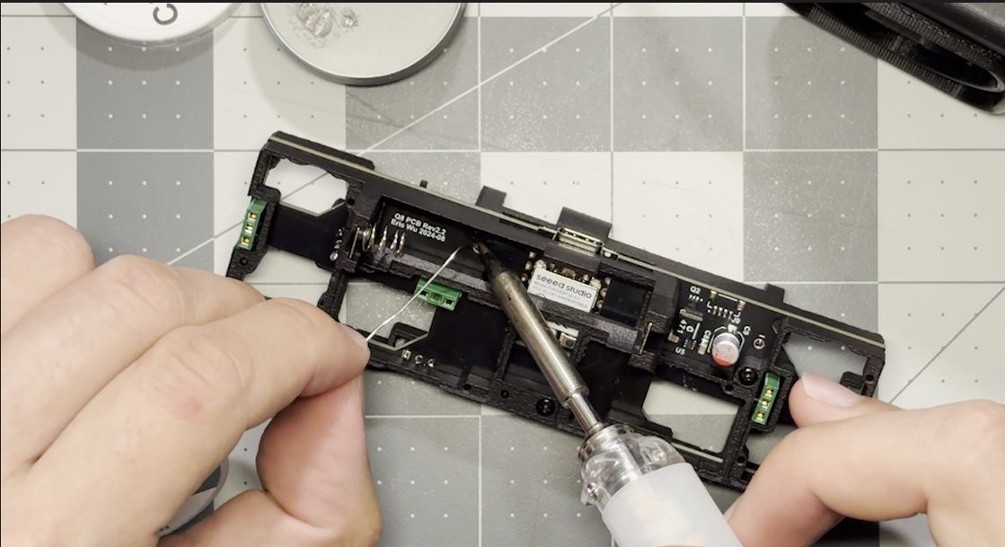
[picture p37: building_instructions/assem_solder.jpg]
Solder
    
</p>

5. Insert ball bearings to the 3D-printed leg links (total: 12 bearings). You might need the back of the screwdriver to lightly push the bearings in.
<p align="center">
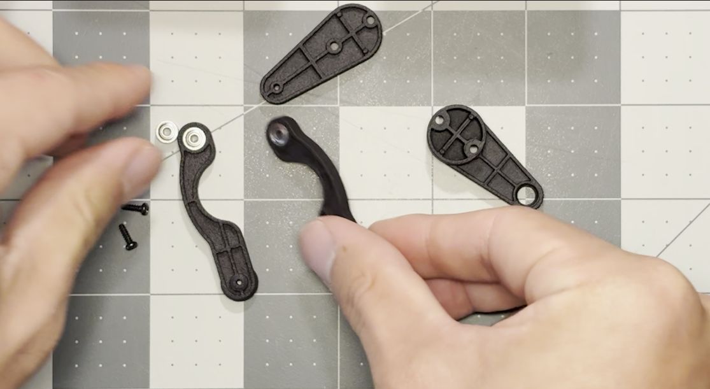
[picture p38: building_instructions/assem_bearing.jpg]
Bearing
    
</p>

6. Assemble legs **(2 pairs that are mirrored to each other)** and set them aside. Each leg uses 3 M2x6mm screws. It might be helpful to first orient the leg parts following the image below without screws, in order to understand the small differences between some parts. Refer to the CAD model for better clarification. When finished, put the assembled legs aside and we'll come back to them later.
<p align="center">
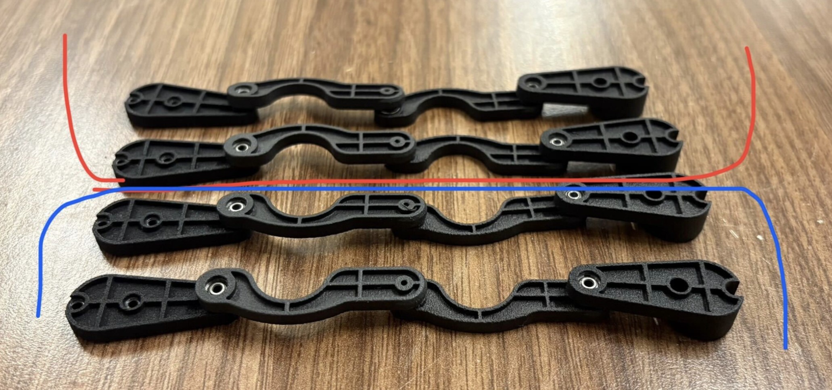
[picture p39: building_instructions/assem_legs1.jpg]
Legs
    
</p>

- For each leg, position the leg elements as indicated and insert the bottom screw. Flip this setup and install the other 2 screws.
<p align="center">
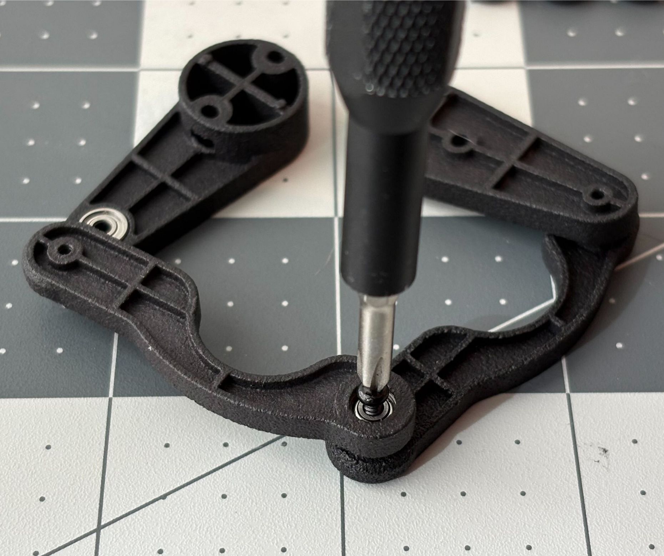
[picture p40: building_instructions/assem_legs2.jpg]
Assemble legs
    
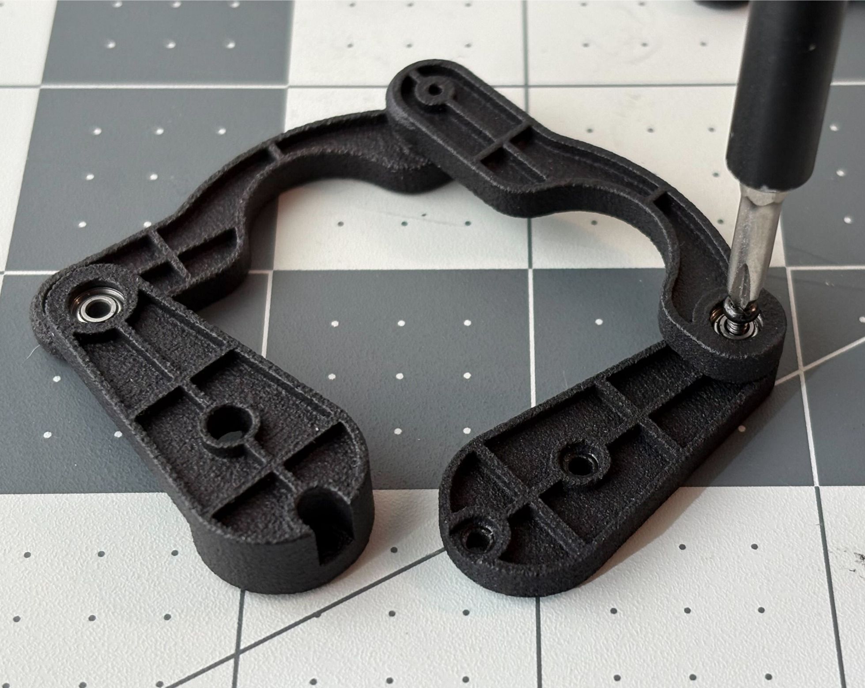
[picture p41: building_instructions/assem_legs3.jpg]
Assemble legs
    
</p>

7. We will move onto installing the DYNAMIXEL motors. To make handling the motors easier in the following steps, it is recommended to place a piece of tape on each motor between in the location indicated below. Detach the bottom shells from ALL 8 motors by loosening the 4 screws as shown in the following image, exposing the electronics. The tape we applied earlier will help prevent the top shells from falling off.
<p align="center">
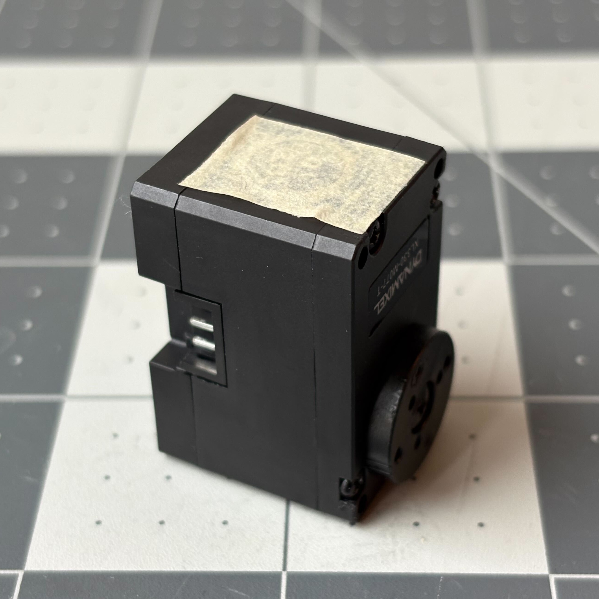
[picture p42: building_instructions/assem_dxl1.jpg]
    
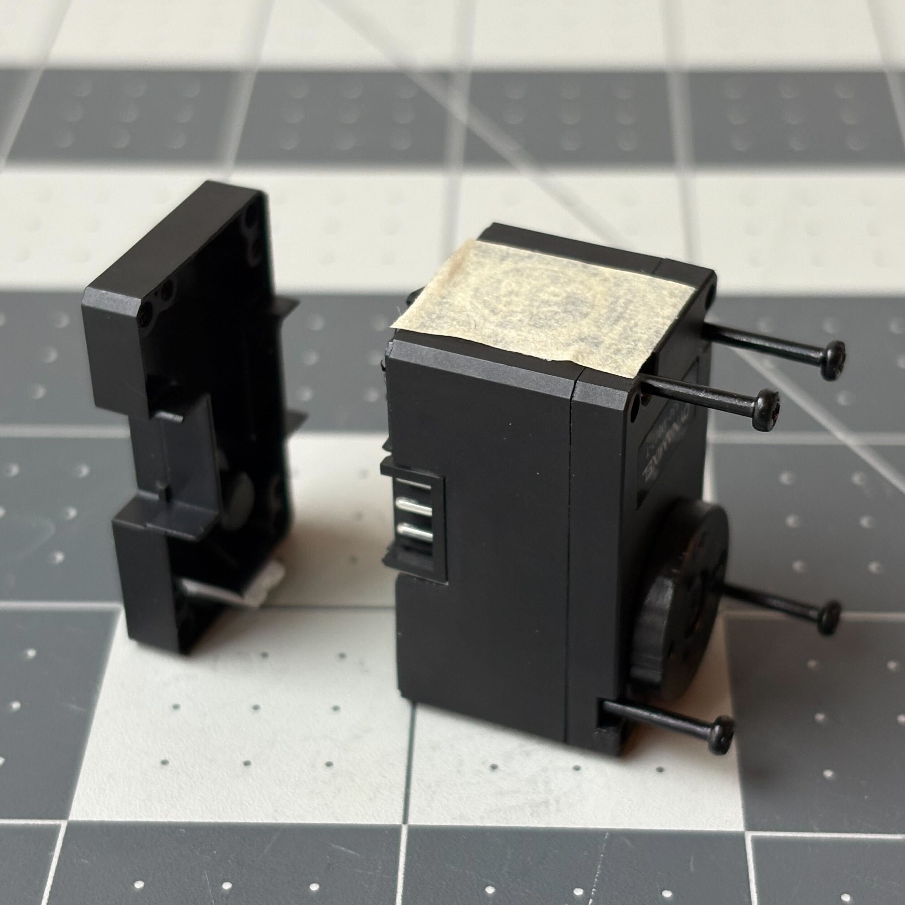
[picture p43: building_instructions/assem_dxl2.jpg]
    
</p>

8. Install the batteries. Make sure the negative side goes to the clip with spring, and the positive side goes to the flat clip.

9. Locate the switch and slide it toward the USB-C port to turn on the power. If your PCB has been assembled correctly, you should see the onboard LED of the Seeed Studio XIAO board light up.

**Note: The following motor setup instructions only works if you have brand new DYNAMIXEL motors that has not been configured before. If you are re-using the motors from previous projects, you will have to manually configure them using by following this instruction: [DXL_config_manual](DXL_config_manual.md).**

10. The next steps involve the use of [PlatformIO](https://platformio.org/) on Microsoft Visual Studio Code to configure the smart servo motors. If you haven't used it before, please refer to their official documentation and tutorials to setup the environment. Download or clone the q8bot repository to open this folder: `q8bot_cpp/q8bot_motor_config`. With your battery installed and power turned on, connect your Q8bot PCB to your laptop using a USB-C cable.

11. Select the correct COM port by clicking the button circled in read, or leave it as "Auto" which will detect the correct port most of the time.
<p align="center">
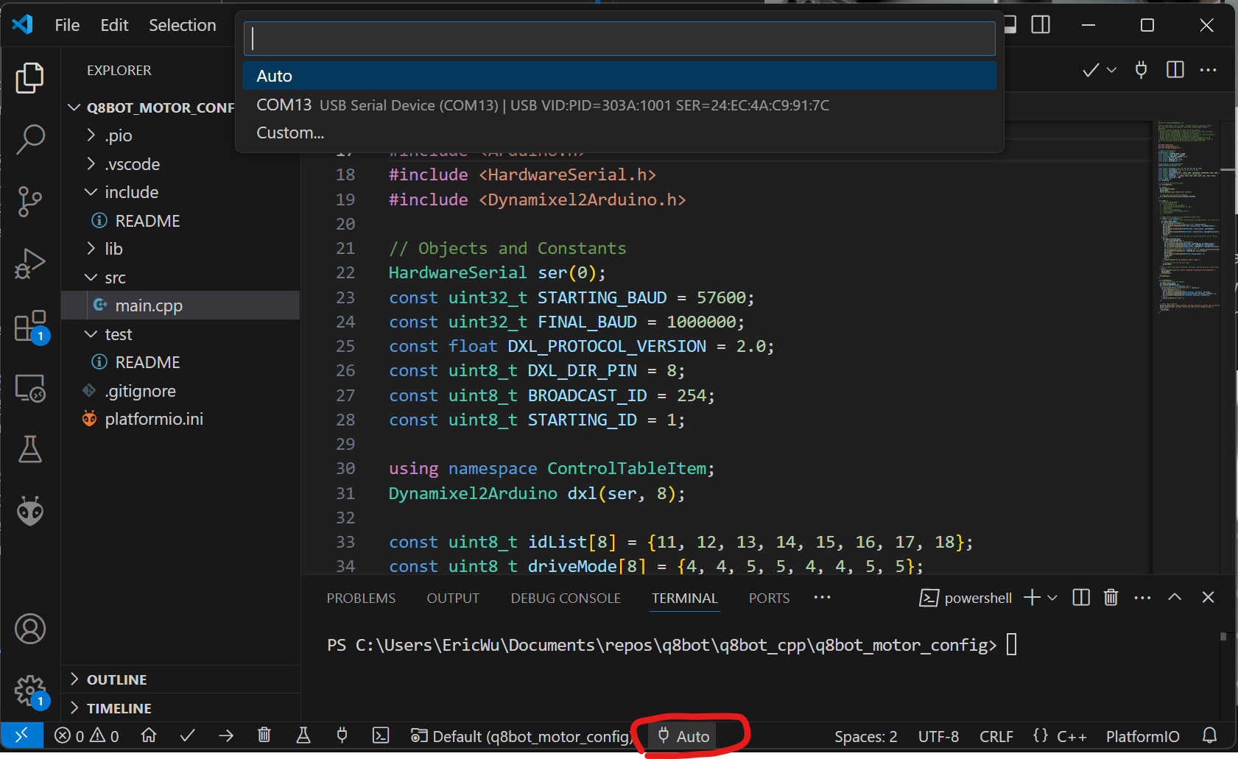
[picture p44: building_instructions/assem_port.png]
    
</p>

12. Upload the q8bot_motor_config firmware to the Q8bot PCB by clicking the button with an arrow shape (circled in read).
<p align="center">
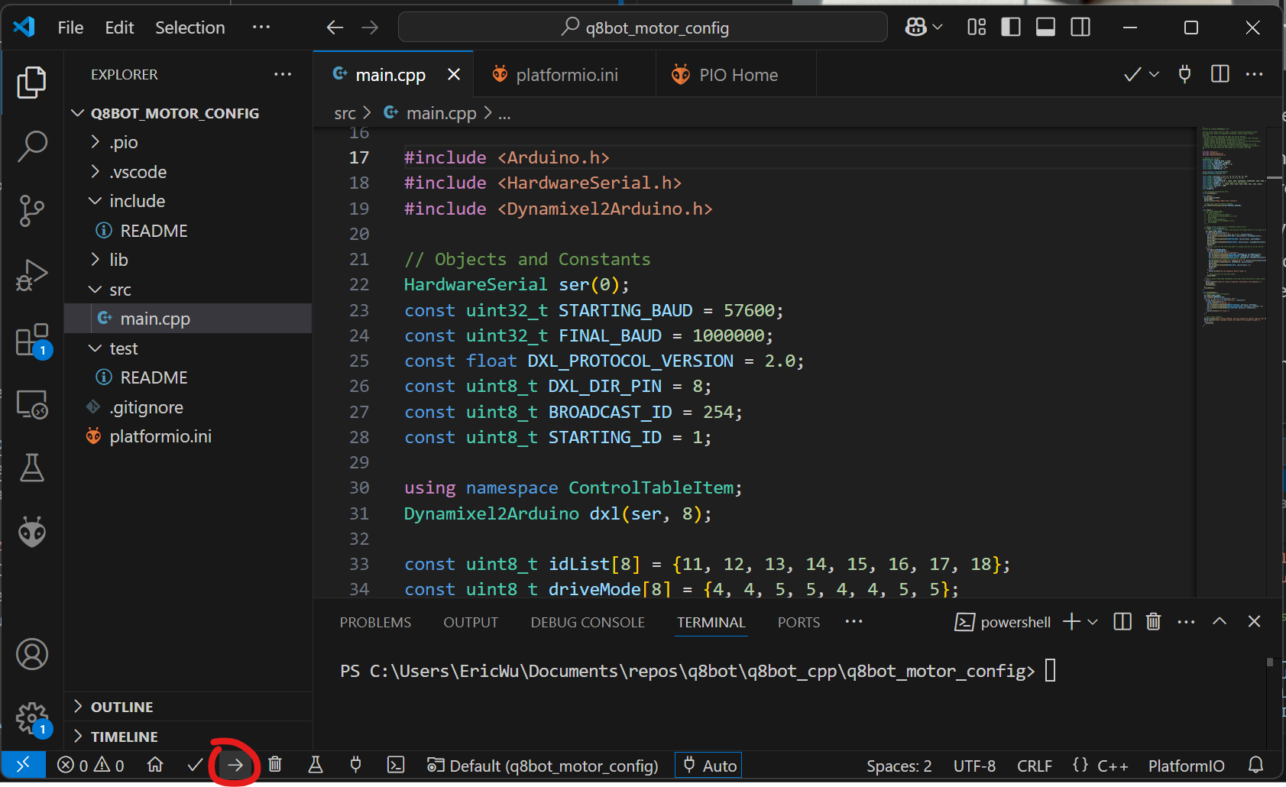
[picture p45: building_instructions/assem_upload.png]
    
</p>

13. If upload is successful, proceed to open the serial monitor by clicking the button with the shape of a cable plug.
<p align="center">
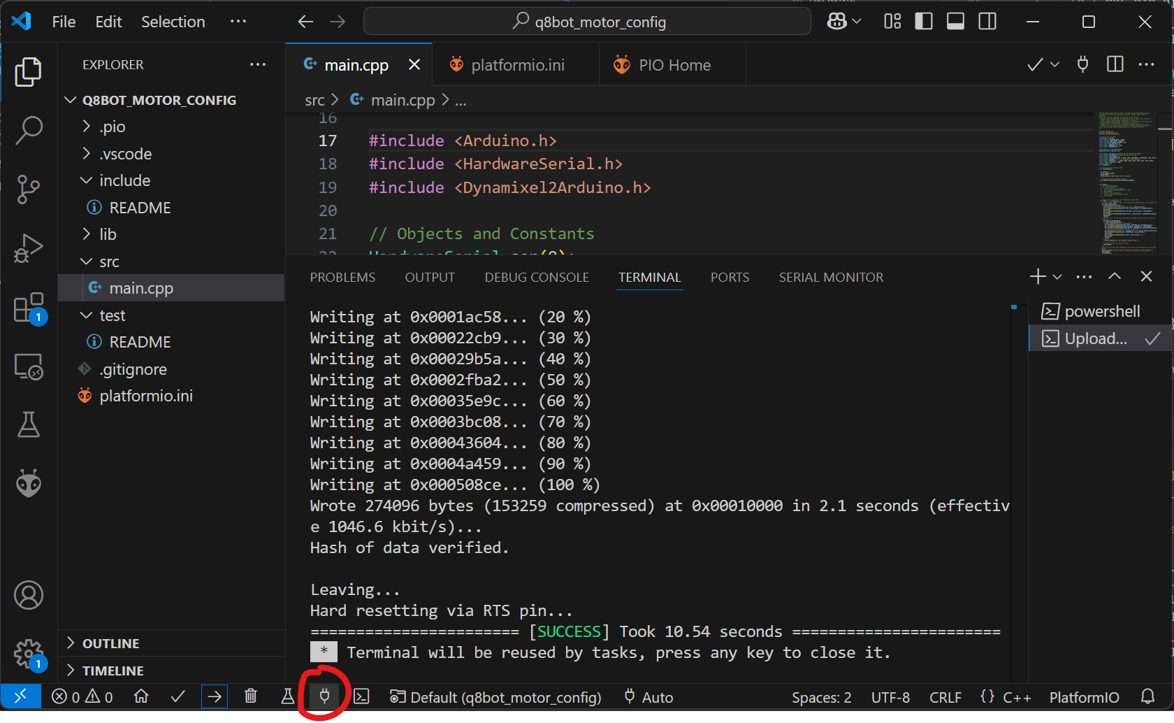
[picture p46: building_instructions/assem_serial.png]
    
</p>

14. In the serial monitor, you should see the message "No new Dynamixel motors found" being printed out every 5 seconds or so.
<p align="center">
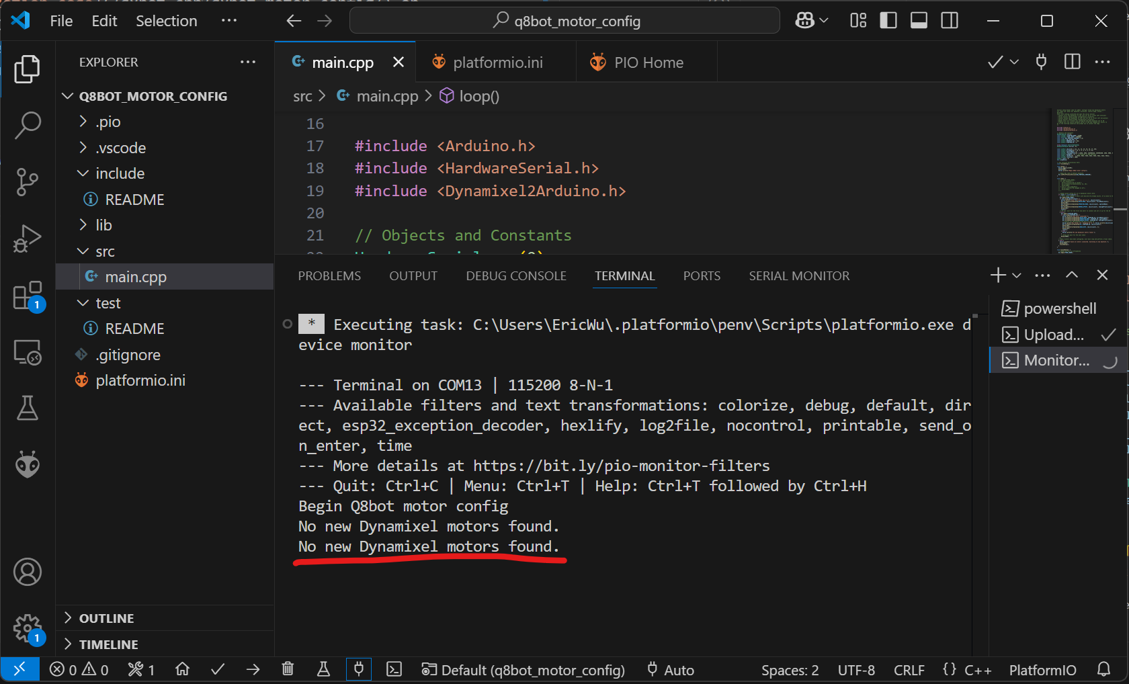
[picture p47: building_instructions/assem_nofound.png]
    
</p>

15. We will be attaching the motors and configuring each of them at the same time. Grab one of the new motors with its back shell removed, and locate the location of the PCB marked with "ID 11" (the latest published Gerber should have the IDs printed on the silkscreen layer as opposed to a separate label as shown in the image).
<p align="center">
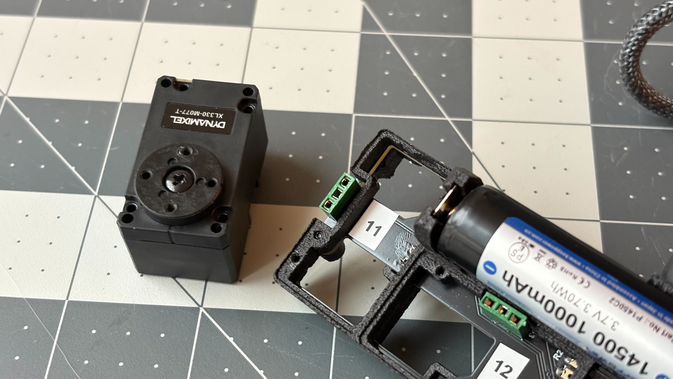
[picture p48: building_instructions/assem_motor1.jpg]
    
</p>

16. Align the PCB headers with the motor pins and install the first motor without screwing the motor in place. As soon as the first new motor is connected, you should see the following message in the laptop's serial monitor: 

    ```New motor connected! DXL Params set. Changing ID to 11.```
<p align="center">
    <img src="assem_motor2.jpg" width="90%">
</p>

17. You may now use the long screws from detaching the shells to secure the first motor in place. Note that only 2 screws are needed instead of 4.
<p align="center">
    <img src="assem_motor3.jpg" width="90%">
</p>

18. Repeat steps 15-17 for the remaining motors: ID12 - ID18. Reminder to follow the labeling numbers sequentially, as the calibration code is written to only look for the next available motor.
<p align="center">
    <img src="assem_motor4.jpg" width="90%">
</p>

19. Once all motors are connected, the program should automatically move all motors in preparation for leg installation. You may disconnect the robot from the laptop now, but keep it powered on.
<p align="center">
    <img src="assem_motorcomplete.jpg" width="90%">
</p>

20. Install the legs. Make sure one identical pair of legs is installed on the left, and the other mirrored pair on the right. Refer to the CAD model of the robot if you find this confusing.
<p align="center">
    <img src="assem_attachlegs.jpg" width="90%">
</p>

Congratulations! You have finished assembling your Q8bot. You may turn off the robot power now, or directly proceed to [Software Setup](software_setup.md).

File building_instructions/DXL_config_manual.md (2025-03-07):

# Manual Dynamixel Motor Configuration

## Identify the front of the robot:
The "Front" silkscreen marking on the front side of the PCB is the front of the actual robot. When the robot is pointing forward, the Seeed XIAO board and most of the electronics are facing left.

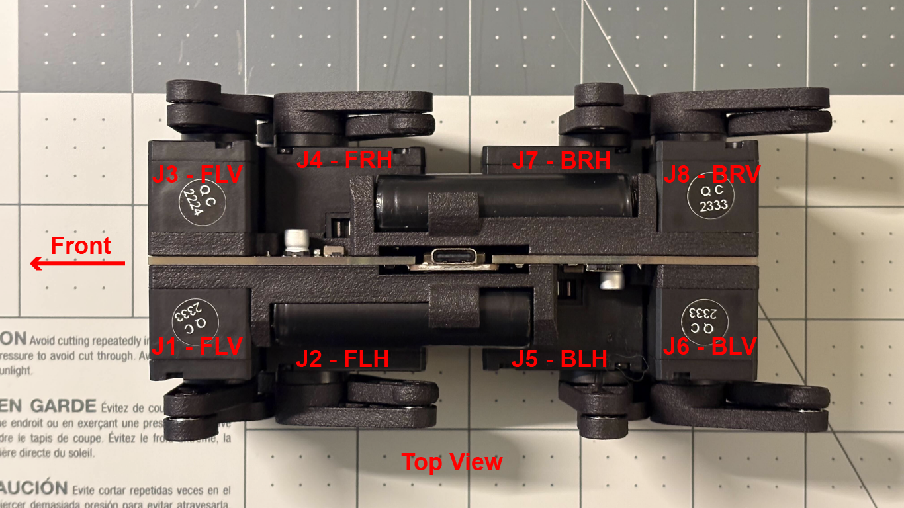
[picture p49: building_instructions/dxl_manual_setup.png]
Q8bot


## Robot joint assignment
**Note: On the image above, J1 is equivalent to J11, J2 is equivalent to J12, etc.**

Using Dynamixel Wizard 2.0 and an U2D2 hub, configure each motor's ID, baudrate, and other parameters before mounting them to the robot.

J1 (front left vertical, FLV): <br>
ID = 11<br>
Baud Rate = 1000000<br>
Drive Mode = Time-based Profile<br>
Operating Mode = Extended Position control<br>
Homing Offset = 2048<br>
**(Only applies when mounting the legs)** When linkage points forward, position should read 360.<br>

J2 (front left horizontal, FLH):<br>
ID = 12<br>
Baud Rate = 1000000<br>
Drive Mode = Time-based Profile<br>
Operating Mode = Extended Position control<br>
Homing Offset = 4096<br>
When linkage points downward, position should read 450.<br>

J3 (front right vertical, FRV): <br>
ID = 13<br>
Baud Rate = 1000000<br>
Drive Mode = Time-based Profile, Reverse mode<br>
Operating Mode = Extended Position control<br>
Homing Offset = 2048<br>
When linkage points forward, position should read 360.<br>

J4 (front right horizontal, FRH):<br>
ID = 14<br>
Baud Rate = 1000000<br>
Drive Mode = Time-based Profile, Reverse mode<br>
Operating Mode = Extended Position control<br>
Homing Offset = 4096<br>
When linkage points downward, position should read 450.<br>

J5 (back left horizontal, BLH): <br>
ID = 15<br>
Baud Rate = 1000000<br>
Drive Mode = Time-based Profile<br>
Operating Mode = Extended Position control<br>
Homing Offset = 2048<br>
When linkage points forward, position should read 360.<br>

J6 (back left vertical, BLV):<br>
ID = 16<br>
Baud Rate = 1000000<br>
Drive Mode = Time-based Profile<br>
Operating Mode = Extended Position control<br>
Homing Offset = 4096<br>
When linkage points downward, position should read 450.<br>

J7 (bask right horizontal, BRH): <br>
ID = 17<br>
Baud Rate = 1000000<br>
Drive Mode = Time-based Profile, Reverse mode<br>
Operating Mode = Extended Position control<br>
Homing Offset = 2048<br>
When linkage points forward, position should read 360.<br>

J8 (back right vertical, BRV):<br>
ID = 18<br>
Baud Rate = 1000000<br>
Drive Mode = Time-based Profile, Reverse mode<br>
Operating Mode = Extended Position control<br>
Homing Offset = 4096<br>
When linkage points downward, position should read 450.<br>

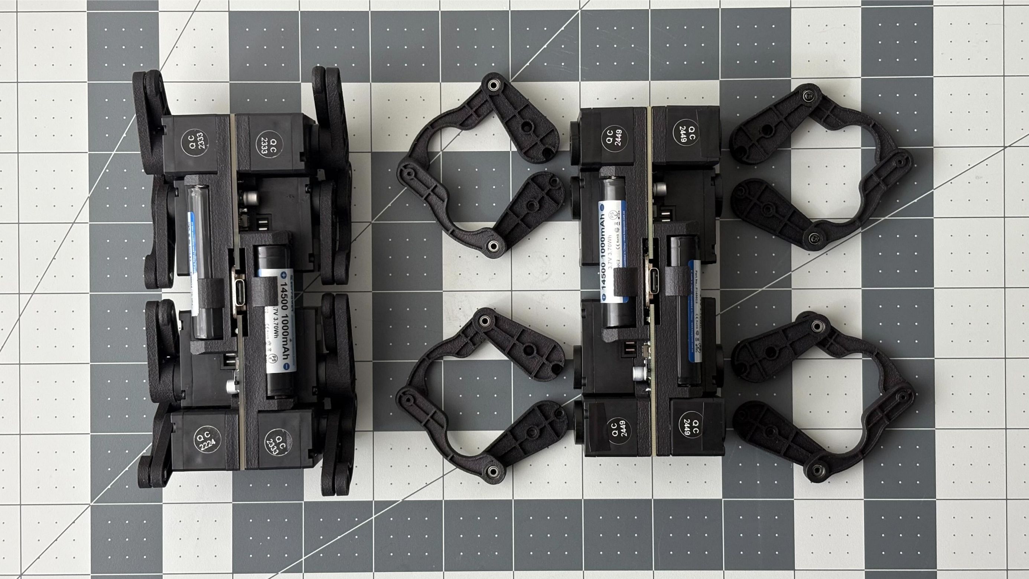
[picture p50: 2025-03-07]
building_instructions/assem_attachlegs.jpg

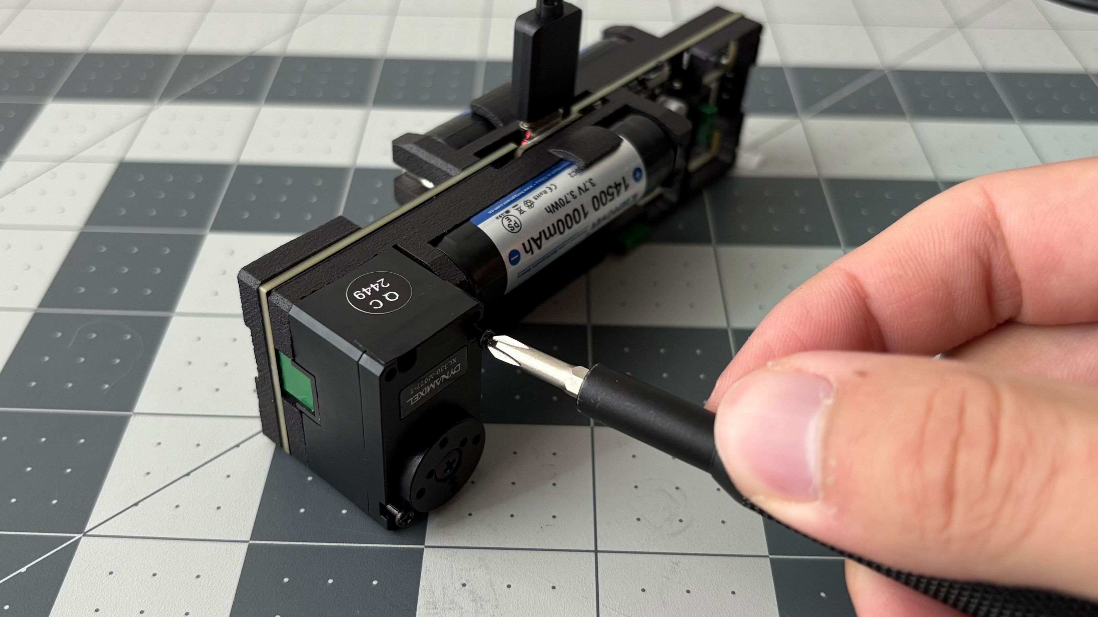
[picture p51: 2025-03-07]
building_instructions/assem_motor3.jpg

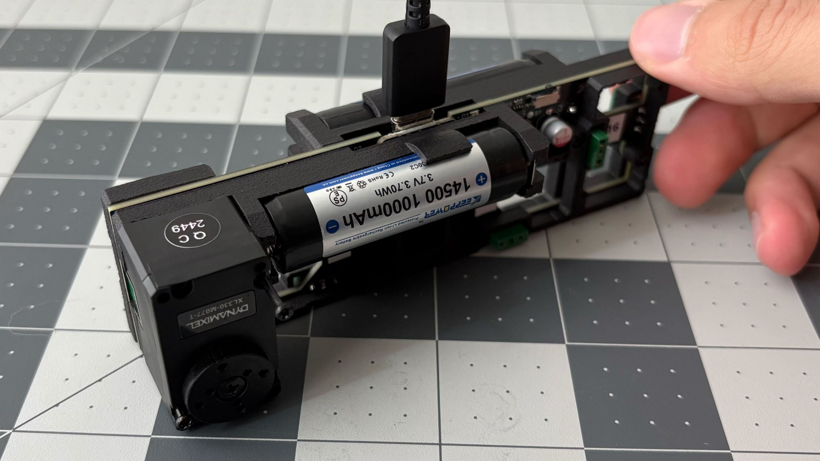
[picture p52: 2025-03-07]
building_instructions/assem_motor2.jpg

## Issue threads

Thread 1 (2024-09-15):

Missing PCB schematic

nithinmathewjoji, 2024-09-15:
Please upload the nessary pcb schematics for better understanding

EricYufengWu, 2025-01-14:
Sorry for the late reply. The latest commit now contains the schematics in PDF: https://github.com/EricYufengWu/q8bot/blob/main/PCBA/Q8_V2.2_Schematics_20250108Export.pdf

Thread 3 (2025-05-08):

能不能搞个其他舵机型号的版本

zhuwei, 2025-05-08:
这些舵机太贵了

EricYufengWu, 2025-05-08:
可以考虑！我选这款舵机主要原因是它是我能找到的最便宜的支持TTL协议的电机。相比纯pwm的舵机，它优势是电机参数可实时调节，并且支持多种操控模式，可以进行更深度的四足控制。如果可以从这款电机做起的话，日后用到更专业的CAN Bus或者RS485的关节电机应该会更容易上手。如果你知道类似并且更便宜的电机，欢迎分享！

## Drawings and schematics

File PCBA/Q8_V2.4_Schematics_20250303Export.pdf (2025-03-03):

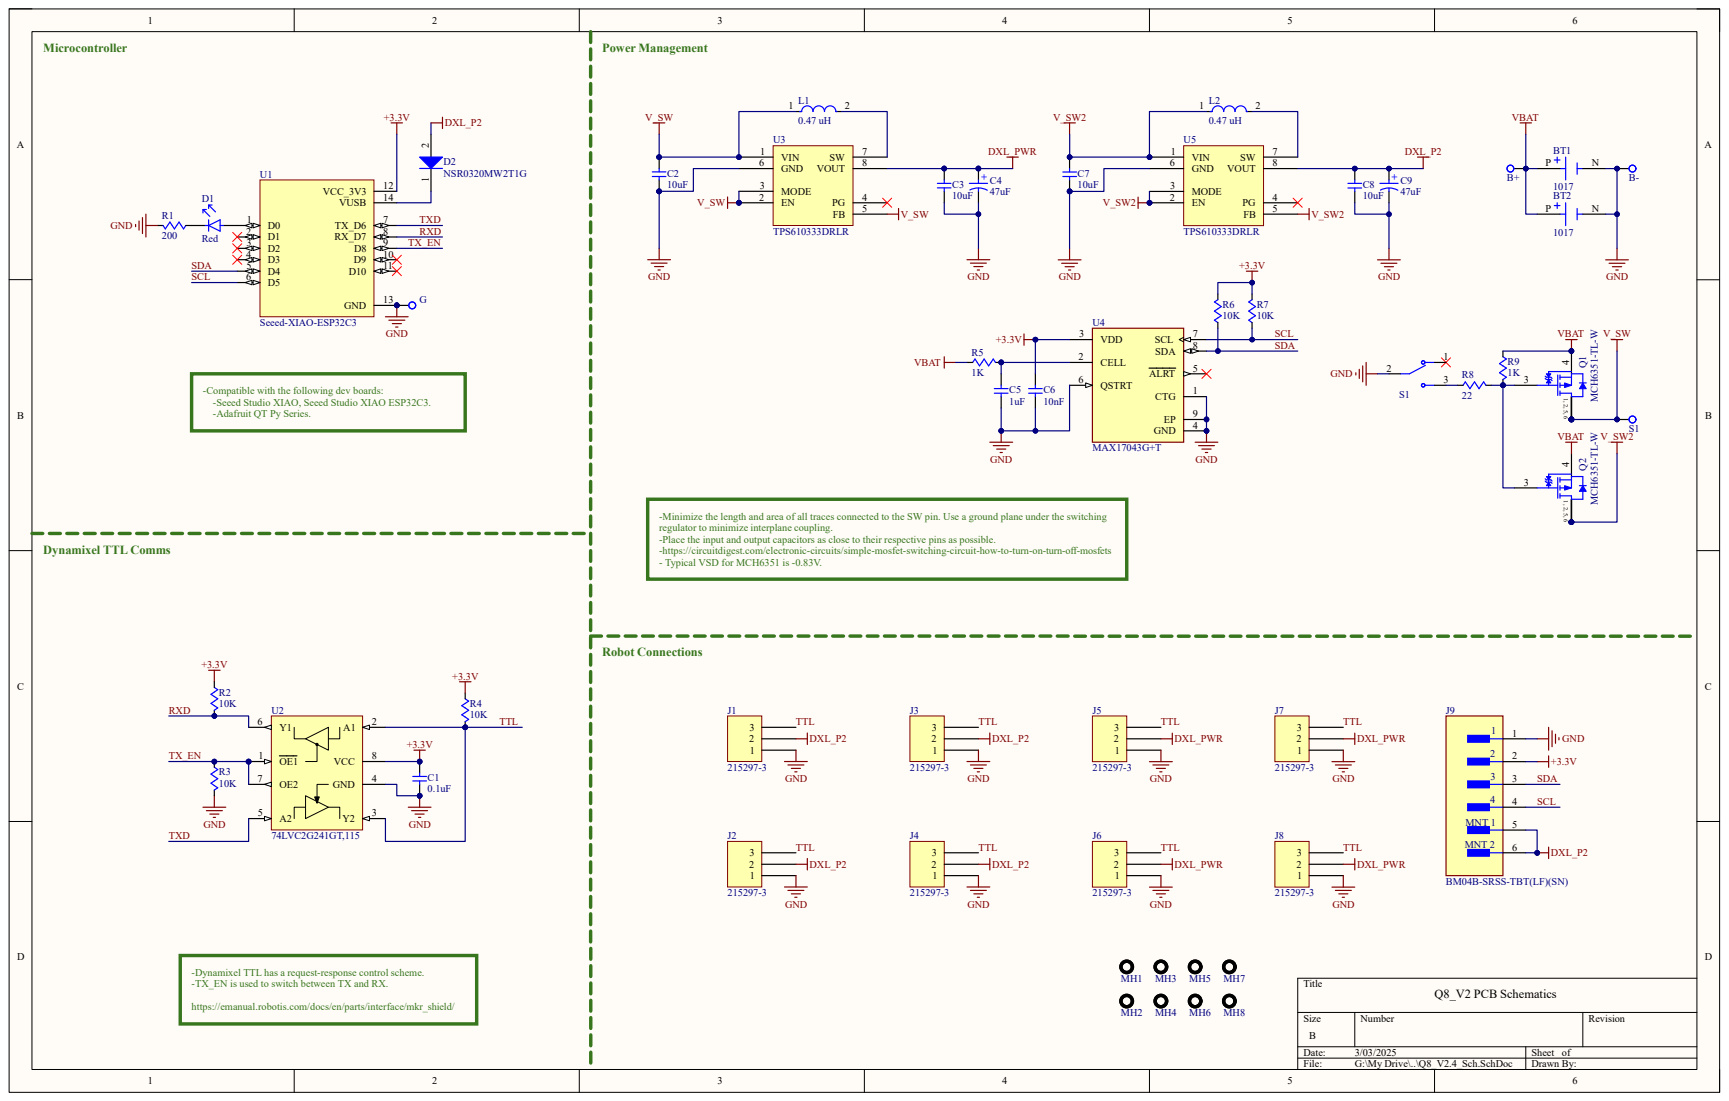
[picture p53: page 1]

-Compatible with the following dev boards:
-Seeed Studio XIAO, Seeed Studio XIAO ESP32C3.
-Adafruit QT Py Series.

-Minimize the length and area of all traces connected to the SW pin. Use a ground plane under the switching
regulator to minimize interplane coupling.
-Place the input and output capacitors as close to their respective pins as possible.
-https://circuitdigest.com/electronic-circuits/simple-mosfet-switching-circuit-how-to-turn-on-turn-off-mosfets
- Typical VSD for MCH6351 is -0.83V.

BM04B-SRSS-TBT(LF)(SN)

-Dynamixel TTL has a request-response control scheme.
-TX_EN is used to switch between TX and RX.

https://emanual.robotis.com/docs/en/parts/interface/mkr_shield/

Size B | Number | Revision

Date: 3/03/2025 | Sheet of
File: G:\My Drive\..\Q8_V2.4_Sch.SchDoc | Drawn By:

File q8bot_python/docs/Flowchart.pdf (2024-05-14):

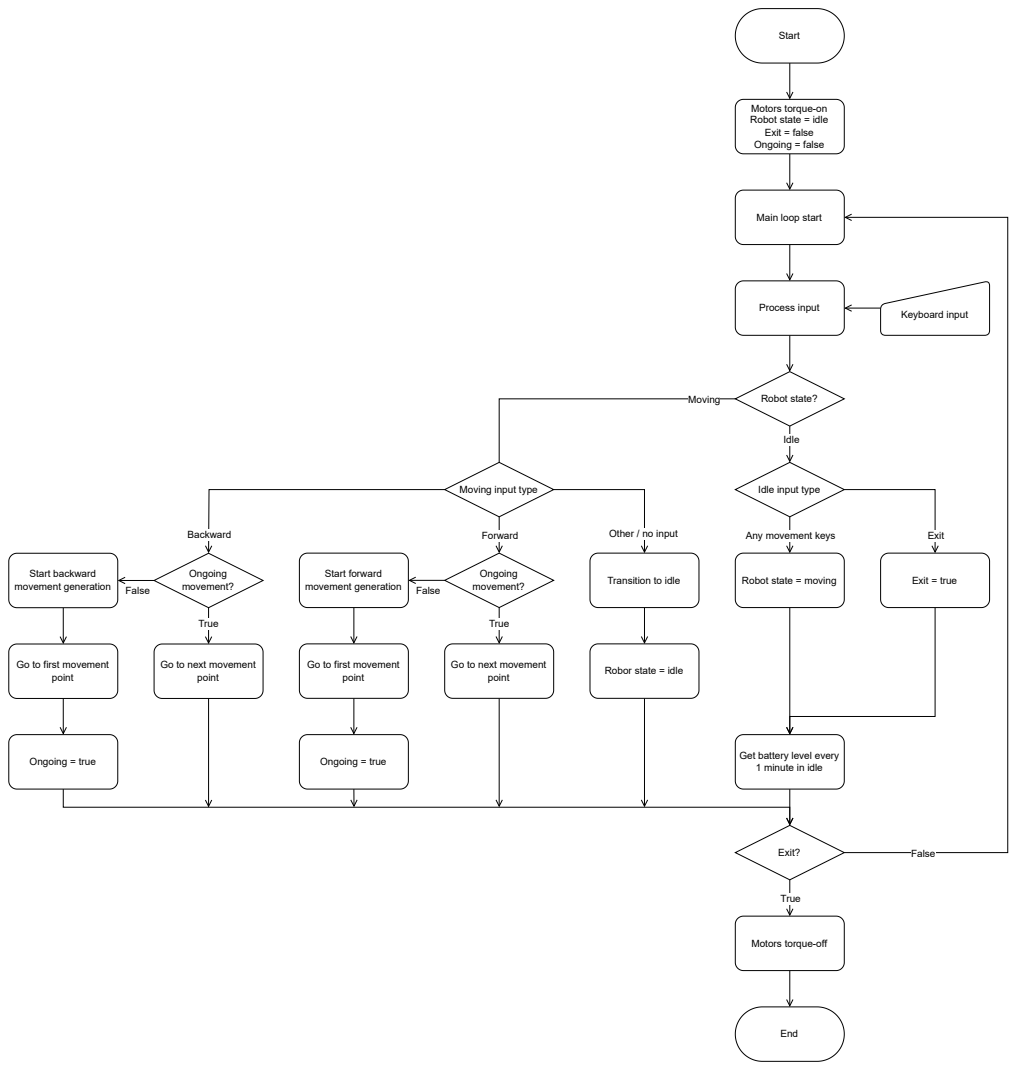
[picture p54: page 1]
True; Exit?; False; Start; End; Idle; Moving; Robot state?; Keyboard input; Any movement keys; Exit; Robot state = moving; Exit = true; Process input; Forward; Backward; Other / no input; Ongoing movement?; point; Start forward movement generation; Ongoing = true; Start backward movement generation

Motors torque-on
Robot state = idle
Exit = false
Ongoing = false

Main loop start

Moving input type

Idle input type

Other / no input
Transition to idle

Go to first movement

Go to next movement

Robor state = idle

Get battery level every
1 minute in idle

Motors torque-off

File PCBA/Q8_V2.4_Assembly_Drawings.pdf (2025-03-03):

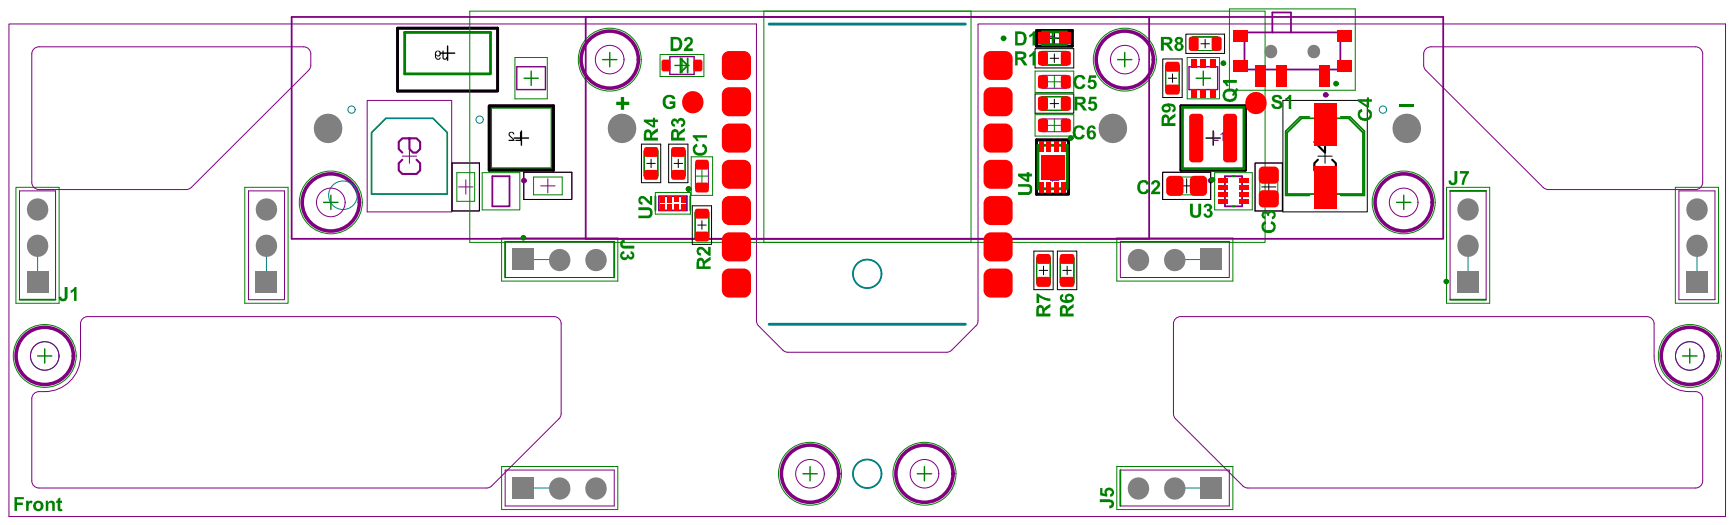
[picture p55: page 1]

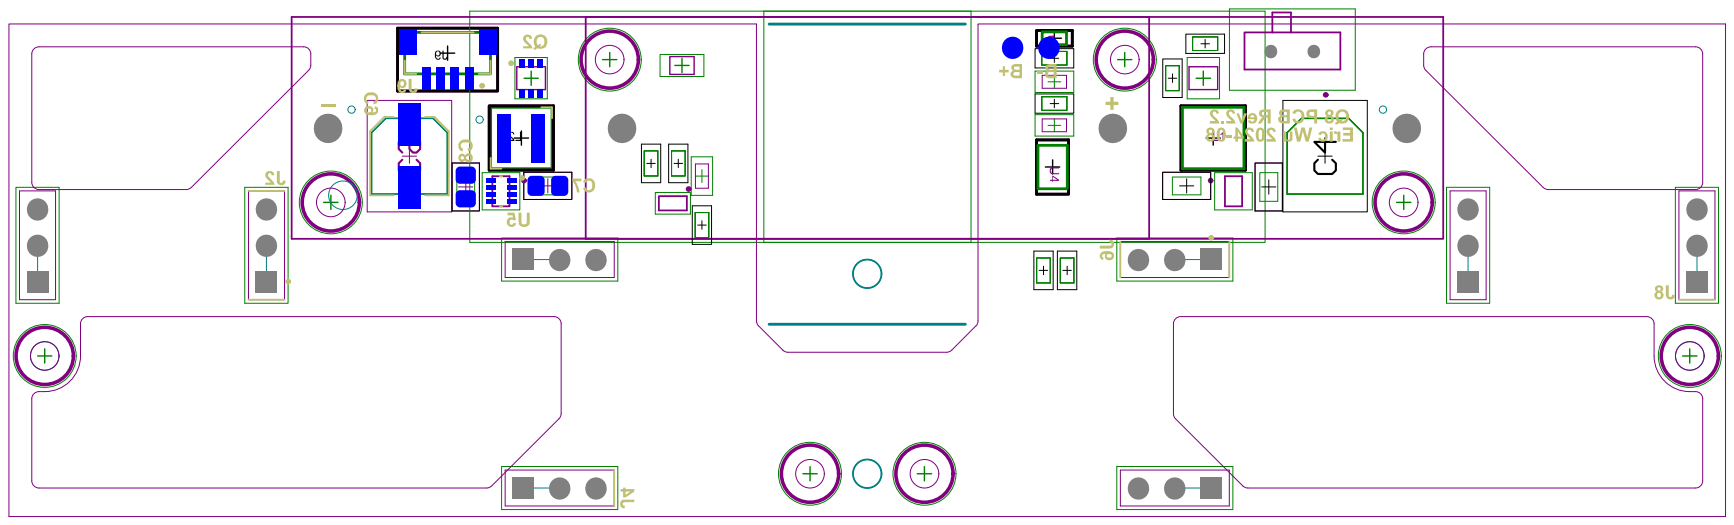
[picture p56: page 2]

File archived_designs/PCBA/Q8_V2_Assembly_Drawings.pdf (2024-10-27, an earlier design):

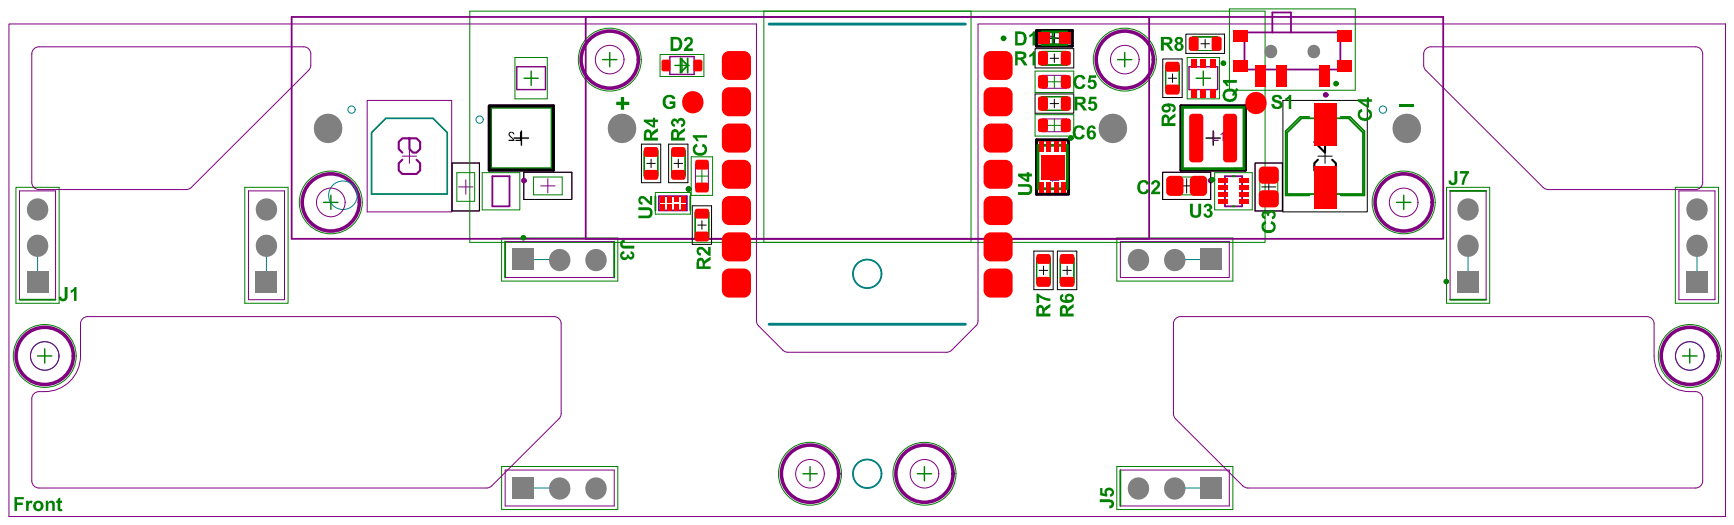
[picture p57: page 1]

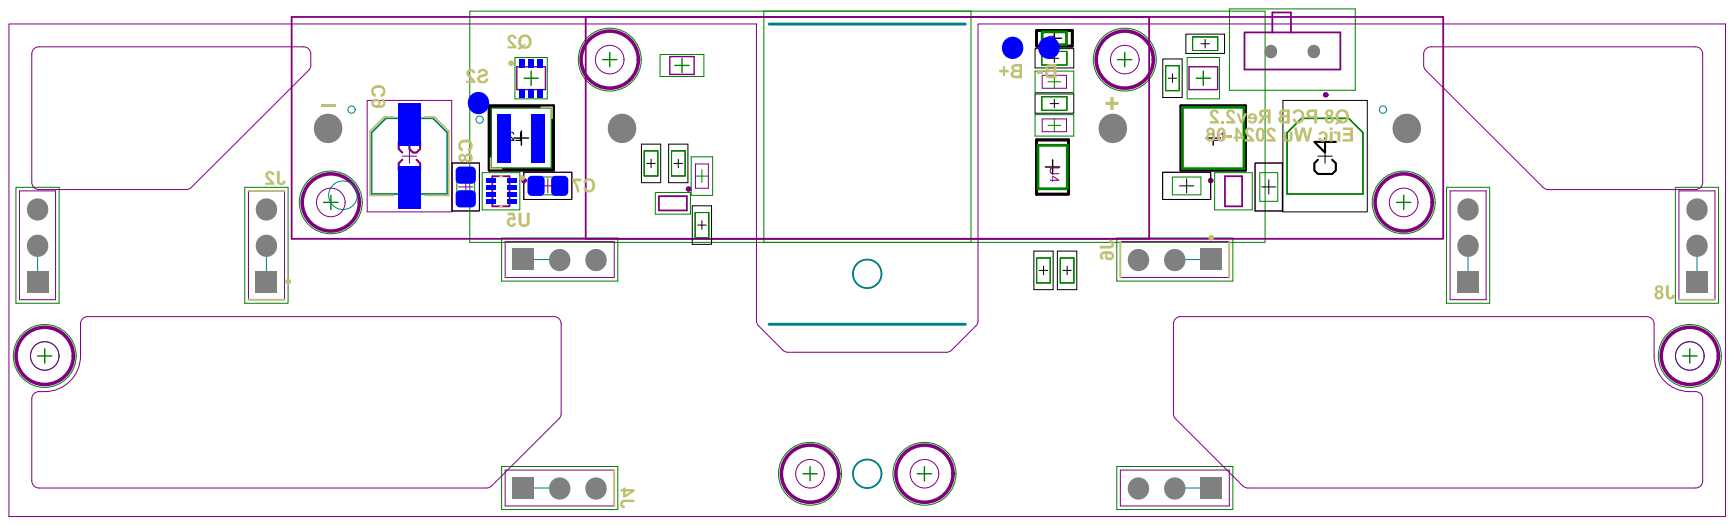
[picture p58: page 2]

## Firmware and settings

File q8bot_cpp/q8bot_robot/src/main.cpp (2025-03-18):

#include <Arduino.h>
#include <WiFi.h>
#include <Wire.h>
#include <Dynamixel2Arduino.h>
#include <ESPNowW.h>
#include <MAX17043.h>
#include "q8Dynamixel.h"

// Change this to your controller's MAC address if doing bi-directional ESPNow
uint8_t receiver_mac[] = {0xEC, 0xDA, 0x3B, 0x36, 0x10, 0xF0};
// uint8_t receiver_mac[] = {0xEC, 0xDA, 0x3B, 0x38, 0x0C, 0x1C};

// ESPNow
uint16_t myData[100];
char theirData[100];
bool incoming = false;
esp_now_peer_info_t peerInfo;
// Dynamixel
HardwareSerial ser(0);
Dynamixel2Arduino q8dxl(ser, 8); // DIR pin on Q8bot is 8
q8Dynamixel q8(q8dxl);
bool recordData = false;
size_t masterSize;
size_t smallerSize = 4;
uint16_t* rData = nullptr;
// LED
const uint8_t LED_PIN = D0;
const uint8_t MODE_PIN = D3;
// MAX17043
float raw;
char intStr[10];

// Callback when data is received
void onRecv(const uint8_t *mac_addr, const uint8_t *incomingData, int len) {
  // char macStr[18];
  // snprintf(macStr, sizeof(macStr), "%02x:%02x:%02x:%02x:%02x:%02x",
  //          mac_addr[0], mac_addr[1], mac_addr[2], mac_addr[3], mac_addr[4],
  //          mac_addr[5]);
  memcpy(&theirData, incomingData, sizeof(theirData));
  // Serial.print("Received from ["); Serial.print(macStr); Serial.print("]: "); 
  // Serial.println(theirData);
  uint8_t result = q8.parseData(theirData);
  if (result == 0) {  // No special instruction.
    return;
  } else {
    switch (result) {
      case 1:
        Serial.println("Send battery level");
        myData[0] = (uint16_t)FuelGauge.percent();
        esp_now_send(receiver_mac, (uint8_t *) &myData, sizeof(myData));
        return;

      case 2: {
        // Serial.print("Record data: ");
        uint16_t* posArray = q8.syncRead();

        // If rData is not nullptr, continue appending posArray to it
        if (rData != nullptr) {
          rData = (uint16_t*)realloc(rData, (masterSize + smallerSize) * sizeof(uint16_t));
          for (size_t j = 0; j < smallerSize; ++j) {
            rData[masterSize + j] = posArray[j];
          }
          masterSize += smallerSize;
        } else {
          // If rData is nullptr, initialize it for the first time
          rData = new uint16_t[smallerSize];
          for (size_t j = 0; j < smallerSize; ++j) {
            rData[j] = posArray[j];
          }
          masterSize = smallerSize;
        }

        // for (size_t j = 0; j < smallerSize; ++j) {
        //     Serial.print(posArray[j]); Serial.print(" ");
        // } Serial.println();
        delete[] posArray;
        return; }

      case 3:
        Serial.println("All recorded data: ");
        if (rData != nullptr) {
          for (size_t i = 0; i < masterSize; ++i) {
            Serial.print(rData[i]);
            Serial.print(" ");
          } Serial.println();
          size_t totalSize = masterSize;  // total data in rData
          size_t chunkSize = 100;  // Chunk size for each ESPNow send
          size_t offset = 0;  // To track the position in rData

          // Loop to send the data in chunks
          while (offset < totalSize) {
            // If rData is less than chunk size then use its size instead.
            size_t currentChunkSize = (totalSize - offset < chunkSize) ? (totalSize - offset) : chunkSize;
            // Copy the chunk from rData to myData
            memcpy(myData, &rData[offset], currentChunkSize * sizeof(uint16_t));
            // If the chunk is smaller than 100, fill the remaining spaces with zeros
            if (currentChunkSize < chunkSize) {
                memset(&myData[currentChunkSize], 0, (chunkSize - currentChunkSize));  // Fill remaining with zeros
            }
            // Send the chunk via ESP-NOW
            esp_now_send(receiver_mac, (uint8_t *)myData, currentChunkSize * sizeof(uint16_t));
            // Updata offset now that the current chunk is sent
            offset += currentChunkSize;
            // Reset myData in preparation for next chunk
            memset(myData, 0, sizeof(myData));
          }

          // Reset rData to nullptr
          delete[] rData;
          rData = nullptr;
          masterSize = 0;  // Reset masterSize as well
        } else {
          Serial.println("No data to send");
        }
        return;
    }
  }
}

// Callback when data is sent. Not used ATM
void OnDataSent(const uint8_t *mac_addr, esp_now_send_status_t status) {
  // Serial.println(status == ESP_NOW_SEND_SUCCESS ? "Delivery Success" : "Delivery Fail");
}

void displayReading()
{
  // MAX17043 Demo code. To be cleaned up
  Serial.println("Device Reading:");
  // Serial.print("Address:       0x"); Serial.println(FuelGauge.address(), HEX);
  // Serial.print("Version:       "); Serial.println(FuelGauge.version());
  // Serial.print("ADC:           "); Serial.println(FuelGauge.adc());
  Serial.print("Voltage:       "); Serial.print(FuelGauge.voltage()); Serial.println(" mV");
  Serial.print("Percent:       "); Serial.print(FuelGauge.percent()); Serial.println("%");
  // Serial.print("Is Sleeping:   "); Serial.println(FuelGauge.isSleeping() ? "Yes" : "No");
  // Serial.print("Alert:         "); Serial.println(FuelGauge.alertIsActive() ? "Yes" : "No");
  // Serial.print("Threshold:     "); Serial.print(FuelGauge.getThreshold()); Serial.println("%");
  // Serial.print("Compensation:  0x"); Serial.println(FuelGauge.compensation(), HEX);
  Serial.println();
}

void addElementToArray(uint16_t*& array, size_t& currentSize, uint16_t newElement) {
    // Allocate a new array with one extra element
    uint16_t* newArray = new uint16_t[currentSize + 1];
    // Add new element to front
    newArray[0] = newElement;
    // Copy the existing elements to the new array
    memcpy(newArray + 1, array, currentSize * sizeof(uint16_t));
    // Delete the old array (free the memory)
    delete[] array;
    // Update the original pointer and size
    array = newArray;
    currentSize++;  // Increment the size of the array
}

void setup() {
  Serial.begin(115200);
  pinMode(LED_PIN, OUTPUT);
  pinMode(MODE_PIN, OUTPUT);

  // // Only needed to grab the MAC address. Disable and upload again.
  // while(!Serial){
  //   delay(100);
  // }
  // Serial.println("Serial port initialized.\n");
  // delay(5000);

  Serial.println("q8bot ESPNOW receiver:");
  WiFi.mode(WIFI_MODE_STA);
  Serial.println(WiFi.macAddress());
  WiFi.disconnect();

  // ESPNow Init
  ESPNow.init();
  ESPNow.reg_recv_cb(onRecv);
  // Register for Send CB. Register pair.
  esp_now_register_send_cb(OnDataSent);
  memcpy(peerInfo.peer_addr, receiver_mac, 6);
  peerInfo.channel = 0;  
  peerInfo.encrypt = false;      
  if (esp_now_add_peer(&peerInfo) != ESP_OK){
    Serial.println("Failed to add peer");
    return;
  }

  // MAX17043
  // Initialize the fuel gauge.
  if (FuelGauge.begin()){
    // Reset the device.
    FuelGauge.reset();
    delay(250);
    // Issue a quickstart command and wait for the device to be ready.
    FuelGauge.quickstart();
    delay(125);
    // Display an initial reading.
    displayReading();
  } else{
    Serial.println("MAX17043 NOT found.\n");
  }

  q8.begin();
  digitalWrite(MODE_PIN, HIGH);
}

void loop() {
  while (!q8.commStart()){
    delay(1000);
    Serial.println("Waiting");
  }
  digitalWrite(LED_PIN, HIGH);
  delay(1000);
  digitalWrite(LED_PIN, LOW);
  Serial.println("Robot start!");

  while(1){
    delay(9800);
    digitalWrite(LED_PIN, HIGH);
    delay(200);
    digitalWrite(LED_PIN, LOW);
    // q8.setProfile(0);
  }
}

/*
New main loop logic
Have an extra parameter to process. Contains the type of info the controller is requesting. Examples include: 
  - Battery level
  - Current reading from the past 5 seconds of the gait
  - IMU reading from the past 5 seconds of the gait (only roll and pitch is ok)
When receiving this command, the robot starts the movement while simultaneous records
data, but hold on to them until the current movement is over. Then after the current 
movement has terminated, it will send the info in bulk to the controller which passes 
all data to the python script. The python script will do all post processing.

If movement duration was less than the duration of data requested, the robot will 
return as much data as there was. Otherwise, it will only send back the most recent 
5-second of data, or something similar depending on what the controller asks.
*/

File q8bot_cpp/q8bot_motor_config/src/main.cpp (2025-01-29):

/*
Written by yufeng.wu0902@gmail.com

Initial setup helper code for q8bot. Configur brand new Dynamixel motors
for robot use: motor ID, baudrate, direction, control mode, offset...
Workflow:
Start with nothing connected and open the serial monitor
- Connect first new Dynamixel to the slot for ID 11 (front left vertical)
- Serial monitor should prompt confuguration successful
- Connect second new Dynamixel to the slot for ID 12 (front left horizontal)
- Serial monitor should prompt configuration successful
- Repeat until all 8 motors are configured and have baudrate set at 1M
- Program will now switch hardware serial to 1Mb and command all joints to 
go to the starting condition and prompt you to install the legs.
*/

#include <Arduino.h>
#include <HardwareSerial.h>
#include <Dynamixel2Arduino.h>

// Objects and Constants
HardwareSerial ser(0);
const uint32_t STARTING_BAUD = 57600;
const uint32_t FINAL_BAUD = 1000000;
const float DXL_PROTOCOL_VERSION = 2.0;
const uint8_t DXL_DIR_PIN = 8;
const uint8_t BROADCAST_ID = 254;
const uint8_t STARTING_ID = 1;

using namespace ControlTableItem;
Dynamixel2Arduino dxl(ser, 8);

const uint8_t idList[8] = {11, 12, 13, 14, 15, 16, 17, 18};
const uint8_t driveMode[8] = {4, 4, 5, 5, 4, 4, 5, 5};
const uint8_t operateMode = 4;
const uint32_t homingOffset[8] = {2048, 4096, 4294965248, 4294963200, 2048, 4096, 4294965248, 4294963200};
const uint8_t baudRate = 3; // Corresponds to 1Mb baudrate
const int32_t idlePos[8]   = {4618, 5622, 4618, 5622, 4618, 5622, 4618, 5622};
const uint16_t moveTime = 1000;
uint8_t count = 0;
bool pingValue;

// put function declarations here:
void finishSetup();

void setup() {
  Serial.begin(115200);
  delay(5000);
  Serial.println("Begin Q8bot motor config");

  // Begin DXL comm at default baudrate
  dxl.setPortProtocolVersion(DXL_PROTOCOL_VERSION);
}

void loop() {
  // Repeat param config for all 8 Dynamixel motors here.
  if (count < sizeof(idList)) {
    // First check whether a motor with desired ID already exists. If so move to the next ID.
    dxl.begin(FINAL_BAUD);
    if (dxl.ping(idList[count])) {
      Serial.printf("Joint %d already set up.\n", idList[count]);
      dxl.writeControlTableItem(DRIVE_MODE, idList[count], driveMode[count]);
      delay(100);
      dxl.writeControlTableItem(OPERATING_MODE, idList[count], operateMode);
      delay(100);
      dxl.writeControlTableItem(HOMING_OFFSET, idList[count], homingOffset[count]);
      delay(100);
      count++;
    // If not, wait for the first new motor to connect and set it up for the ID
    } else {
      dxl.begin(STARTING_BAUD);
      if (dxl.ping(STARTING_ID)) {
        Serial.println("New motor connected!");
        dxl.writeControlTableItem(DRIVE_MODE, STARTING_ID, driveMode[count]);
        dxl.writeControlTableItem(OPERATING_MODE, STARTING_ID, operateMode);
        dxl.writeControlTableItem(HOMING_OFFSET, STARTING_ID, homingOffset[count]);
        // Finally set 1Mb baudrate and move to next ID
        Serial.print("DXL Params set. Changing ID to "); Serial.println(idList[count]);
        dxl.writeControlTableItem(ID, STARTING_ID, idList[count]);
        delay(100);
        dxl.writeControlTableItem(BAUD_RATE, idList[count], 3);
        delay(100);
        count++;
      } else {
        Serial.println("No new Dynamixel motors found.");
      }
      // Delay and wait for the next check
      delay(5000);
    }
  // When 8 motors have been configured, exit main loop and perform a final check.
  } else {
    Serial.println("Leave all motors connected. Switching to new baudrate.");
    delay(5000);
    finishSetup();
  }
}

void finishSetup() {
  // Reopen dxl port at 1M baudrate
  dxl.begin(FINAL_BAUD);
  dxl.torqueOn(BROADCAST_ID);
  for (int i = 0; i < sizeof(idList); i++) {
    Serial.printf("Motor ID %d connection ", idList[i]);
    if (dxl.ping(idList[i])) {
      Serial.println("successful.");
      dxl.writeControlTableItem(PROFILE_VELOCITY, idList[i], moveTime);
      dxl.writeControlTableItem(PROFILE_ACCELERATION, idList[i], moveTime / 3);
      dxl.writeControlTableItem(GOAL_POSITION, idList[i], idlePos[i]);
    } else {
      Serial.println("not found.");
    }
  }

  // Motor setup complete
  Serial.println("Motor setup complete. You may continue to install legs on your Q8bot.");
  Serial.println("When finished, switch the robot off to disable torque.");
  while (1) {
    delay(100);
  }
}

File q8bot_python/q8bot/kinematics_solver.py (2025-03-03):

'''
Written by yufeng.wu0902@gmail.com

Python class for FK/IK calculations on Q8bot.
'''

import math
import numpy as np
from scipy.optimize import fsolve

# d - distance between motors; l1/l1p - upper linkage length; l2/l2p - lower linkage length
# Unit is in mm.
class k_solver:
    def __init__(self, d = 19.5, l1 = 25, l2 = 40, l1p = 25, l2p = 40):
        self.d = d
        self.l1 = l1
        self.l2 = l2
        self.l1p = l1p
        self.l2p = l2p
        self.prev_ik = [45, 135]
        self.prev_est = [self.d/2, (self.l1 + self.l2)]

    # Check whether a solution exist. To be completed later.
    def ik_check(self, x, y):
        if y < 0:
            return False
        return True

    # Solve inverse kinematics at an given end effector position
    def ik_solve(self, x, y, deg = True, rounding = 3):
        try:
            c1 = math.sqrt((x - self.d)**2 + y**2)
            c2 = math.sqrt(x**2 + y**2)
            a1 = math.acos((c1**2 + self.d**2 - c2**2) / (2*c1*self.d))
            a2 = math.acos((c2**2 + self.d**2 - c1**2) / (2*c2*self.d))
            b1 = math.acos((c1**2 + self.l1**2 - self.l2**2) / (2*c1*self.l1))
            b2 = math.acos((c2**2 + self.l1p**2 - self.l2p**2) / (2*c2*self.l1p))
            q1 = math.pi - a1 - b1
            q2 = a2 + b2
            if deg:
                q1, q2 = q1*180/math.pi, q2*180/math.pi
            self.prev_ik = [q1, q2]
            return np.round(q1, rounding), np.round(q2, rounding), True
        except:
            return self.prev_ik[0], self.prev_ik[1], False
    
    # Check whether a solution exist. To be completed later.
    def fk_check(self):
        return True
    
    # Solve inverse kinematics at an given end effector position
    def fk_solve(self, q1, q2, deg = True, rounding = 3):
        if deg:
            angles = (self._deg2rad(q1), self._deg2rad(q2))
        x, y = fsolve(self._fk_calc, [10,60], args=angles)
        # x, y = fsolve(self._fk_calc, self.prev_est, args=angles)
        # self.prev_est = [x, y]
        return round(x, rounding), round(y, rounding)

    #-------------------#
    # Private Functions #
    #-------------------#
    def _fk_calc(self, x, *angle):
        q1, q2 = angle
        Xa = self.l1 * math.cos(q1) + self.d
        Ya = self.l1 * math.sin(q1)
        Xb = self.l1p * math.cos(q2)
        Yb = self.l1p * math.sin(q2)
        return [x[0]*x[0] - 2*x[0]*Xa + Xa**2 + x[1]*x[1] - 2*x[1]*Ya + Ya**2 - self.l2**2,
                x[0]*x[0] - 2*x[0]*Xb + Xb**2 + x[1]*x[1] - 2*x[1]*Yb + Yb**2 - self.l2p**2]
    
    def _rad2deg(self, ang_rad):
        return ang_rad*180/math.pi
    
    def _deg2rad(self, ang_deg):
        return ang_deg*math.pi/180

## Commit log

2023-11-12 Initial Tests
    One leg jumping tests
2023-12-10 Leg read and README
2023-12-17 kinematics solver class
2024-04-19 bulk write test 8 motors
2024-04-23 wrapper class 8 motor test
2024-04-25 basic wireless walking
2024-09-29 started amber height adjustment
    started working on incorporating gait height adjustment, have yet to rule out edge cases so too high/too low initial xy will cause undesirable movements.
    [q8_operate.py, q8_operate_pymove.py, q8_operate_pywalk.py]
2024-10-27 Open sourced hardware
    [Pick Place for Q8_V2.2_Brd (Detail).csv, Pick Place for Q8_V2.2_Brd (Simplified).xlsx, Q8_V2.2_Open_Source.PrjPcb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]
2025-01-08 Updated BOM and schematics
    small error in BOM/schematic regarding U2
    [Pick Place for Q8_V2.2_Brd (Detail).csv, Pick Place for Q8_V2.2_Brd (Read Friendly).xlsx, Pick Place for Q8_V2.2_Brd (Simplified).xlsx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]
2025-01-17 exp01
    Leg experiment code. Added sync read to python class.
2025-01-28 More gaits and motor init code
2025-01-29 Updated motor config
2025-02-14 Dev
    Plotting returned data from q8bot (single leg)
2025-03-03 Updated CAD and README
    [692ZZ_Ball_Bearing_20250303export.SLDPRT, Batt_Case_keystone-PN1087_20250303export.SLDPRT, Batt_Clip_keystone-PN1087-1_20250303export.SLDPRT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]
2025-07-26 updated BOM
    [Q8_V2.4_BOM_PCBWay.xlsx]
